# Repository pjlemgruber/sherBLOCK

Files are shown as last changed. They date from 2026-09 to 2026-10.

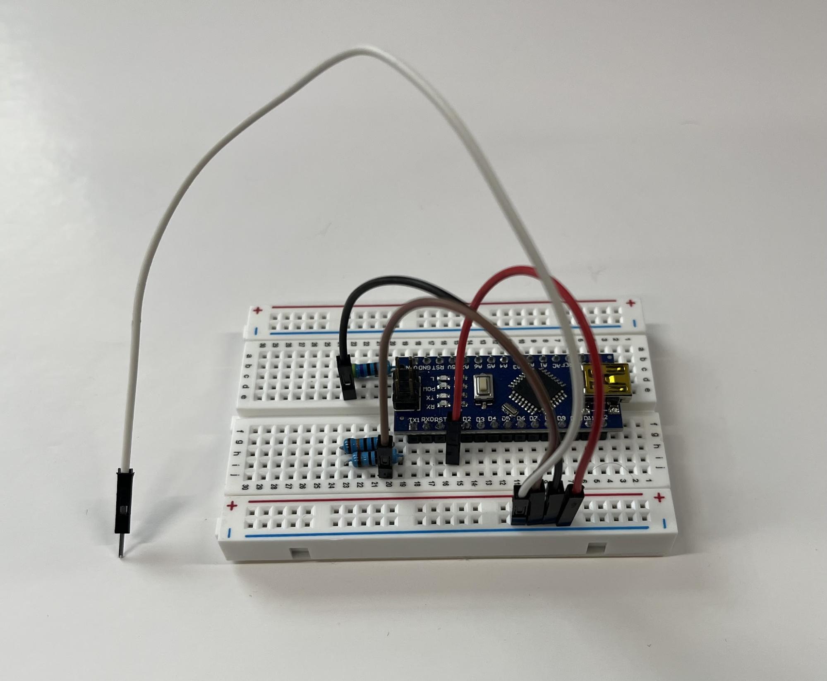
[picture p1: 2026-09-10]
images/image33.jpg

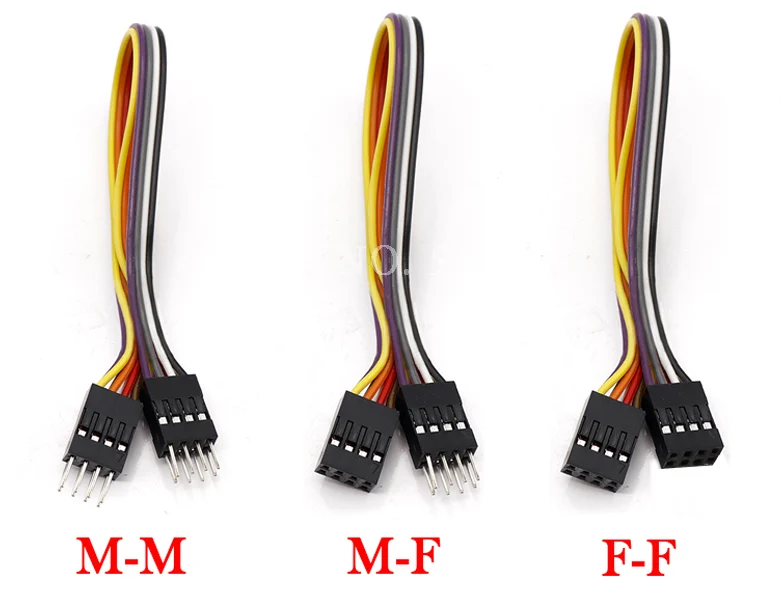
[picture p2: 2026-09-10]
images/image8.png

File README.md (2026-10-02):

# sherBLOCK

<p align="center">
sherBLOCK_5x
</p>

The sherBLOCK is a portable DIY isothermal heater designed for tube incubation in the field. It operates at 12V with a maximum power consumption of 24W, meaning it can be powered by a barrel jack wall adapter or a cigarette lighter car plug. The sherBLOCK is controlled by an Arduino Nano microcontroller, which can be programmed for user-specific modifications that best fit your project's needs. 

The sherBLOCK can be assembled to fit a variety of tube sizes (0.2, 0.5, 1.5, 5, and 15mL tubes). Other components, such as heaters, can also be replaced to meet your demands as long as they fit the sizing specifications of the enclosure. Components that deviate in sizing may require adjustments to the 3D printing files.



We welcome you to make modifications to the sherBLOCK and share them here so others can access them. 

This project is held under the GNU General Public Licence v3.0. Please keep in mind that by choosing to use or engage with the materials of this project, you are doing so at your own risk. The sherBLOCK includes heaters and sensitive electronics, making it a potential fire hazard. Please exercise caution when engaging with the materials provided here and use them responsibly.

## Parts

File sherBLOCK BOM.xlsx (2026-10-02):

sherBLOCK Bill of Materials (BOM) - 24W model |  |  |  |  |  |  | sherBLOCK+ Bill of Materials (BOM) - 80-120W model |  |  |  |  |  |  | Parts of interest for future steps
Materials | Bulk amount | Bulk cost | Amount | Cost | Supplier | Justification | Materials | Bulk amount | Bulk cost | Amount | Cost | Supplier | Justification | Parts | Notes | Link | Link 2 | Link 3
Interactive elements |  |  |  |  |  |  | Interactive elements |  |  |  |  |  |  | Buttons to program temperature/ time |  | https://www.aliexpress.us/item/3256806078303106.html?src=google&gatewayAdapt=glo2usa
Arduino Nano | 2 | $9.99 | 1 | $5.00 | LUIRSAY (https://www.amazon.com/LUIRSAY-2Pcs-ATmega328P-Microcontroller-Compatible/dp/B0F1FQMNXM?s=electronics) | Stores and executes the sherBLOCK code. | Arduino Nano | 2 | $9.99 | 1 | $5.00 | LUIRSAY (https://www.amazon.com/LUIRSAY-2Pcs-ATmega328P-Microcontroller-Compatible/dp/B0F1FQMNXM?s=electronics) | Stores and executes the sherBLOCK code. | Alternate temperature sensor |  | https://www.digikey.com/en/products/detail/dfrobot/DFR0198/7597054?gclsrc=aw.ds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 | https://www.dfrobot.com/product-1354.html
DS18B20 w/ adapter | 2 | $9.99 | 1 | $5.00 | DIYables (https://www.amazon.com/DIYables-Temperature-Raspberry-Waterproof-Stainless/dp/B0BPFYQT8C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) | Registers heating block temperature. | DS18B20 w/ adapter | 2 | $9.99 | 1 | $5.00 | DIYables (https://www.amazon.com/DIYables-Temperature-Raspberry-Waterproof-Stainless/dp/B0BPFYQT8C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) | Registers heating block temperature. | M3 Cap to keep feet level |  | https://www.amazon.com/50pcs-Acorn-Nylon-Decorative-Hexagon/dp/B0CFZR217S | https://www.aftfasteners.com/protective-cap-for-m3-screws-1-pkg/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
12V Heating Plate PTC | 4 | $16.19 | 1 | $4.05 | MECCANIXITY (https://www.amazon.com/MECCANIXITY-Polyimide-Insulated-Temperature-Thermostatic/dp/B0DYDSMS4J) | Heating element. | 12V Heating Plate | 4 | $16.29 | 1 | $4.08 | MECCANIXITY (https://www.amazon.com/MECCANIXITY-Polyimide-Insulated-Temperature-Thermostatic/dp/B0DXTP5M6D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) | High-power heating element. | Stronger heater |  | https://www.amazon.com/Bestol-Heating-consistant-Temperature-Thermostatic/dp/B07VBDT8NL | https://www.amazon.com/MECCANIXITY-Polyimide-Insulated-Temperature-Thermostatic/dp/B0DXTP5M6D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 | https://www.amazon.com/Electric-100x21x5mm-Heating-Element-Thermostatic/dp/B0FY6CPML9
OLED display | 1 | $21.00 | 1 | $21.00 | AITRIP (https://www.amazon.com/AITRIP-Display-SSD1309-Interface-C51-White/dp/B0G384SJ9V?s=electronics) | Displays sherBLOCK information | OLED display | 1 | $23.00 | 1 | $23.00 | AITRIP (https://www.amazon.com/AITRIP-Display-SSD1309-Interface-C51-White/dp/B0G384SJ9V?s=electronics) | Displays sherBLOCK information | Silicone sheet/foam |  | https://www.amazon.com/Exactly-Rubber-Commercial-Grade-Silicone/dp/B0B5V95MRG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 | https://www.amazon.com/LMS-Resistant-Silicone-Texture-Thickness/dp/B09YLRVL3M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 | https://www.ebay.com/itm/336449303839?chn=ps&var=545937298726&google_free_listing_action=view_item
Heat block | 1 | $35.99 | 1 | $35.99 | ONiLAB (https://www.amazon.com/dp/B0BHWKG5C8?tag=usdeexplicits-20&th=1) | Holds and heats up 0.5 mL tubes. | Heat block | 1 | $35.99 | 1 | $35.99 | ONiLAB (https://www.amazon.com/dp/B0BHWKG5C8?tag=usdeexplicits-20&th=1) | Holds and heats up 0.5 mL tubes. | Cork sheet |  | https://www.gigaparts.com/2mm-cork-sheet-4pcs-b-yl001.html?gigadv=P_Max_Best_Prod_Loc_CPA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
Wiring |  |  |  |  |  |  | Mica sheet | 240x150mm | $5.99 | 40x40mm | $0.33 | YQBOOM (https://www.amazon.com/YQBOOM-Waveguide-Universal-Microwave-150X120mm/dp/B0C3LTP2WX) | Insulation from heater. | IPP015N04NF2S | 10A rated logic level mosfet
12V Power Adapter | 1 | $7.29 | 1 | $7.29 | MTYTOT (https://www.amazon.com/100-240V-Converter-Compatible-5-5x2-1mm-Transformer/dp/B0CPLNHQZR?hvadid=693865273627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) | Provides 2A at 12V | Wiring |  |  |  |  |  |  | FQP30N06L | logic level mosfet to replace irf540N | https://www.amazon.com/dp/B0CBKDYHYJ?lv=shuf&channelId=500&plpRedirect=mhFallback
Female Power Jack DC | 5 | $4.99 | 1 | $1.00 | DIYables (https://www.amazon.com/dp/B0BPGC5GTQ?linkId=c76078686dfa517bb173c375dee38373&language=en_US) | Connects components to the power source. | 12V 10A Power Adapter 2.5x5.5mm | 1 | $22.00 | 1 | $22.00 | COOLM (https://www.amazon.com/12V-10A-Power-Suppy-Adapter/dp/B07FFKL7CR) | Provides the citcuit with 10A at 12V.
MOSFET IRF540N N-Channel | 10 | $7.99 | 1 | $0.80 | ALLECIN (https://www.amazon.com/ALLECIN-Transistors-IRF520NPBF-N-Channel-Transistor/dp/B0CBKGPJML) | Controls the power supply to the heating block. | 10A Power Jack connector | 1 | $1.86 | 1 | $1.86 | DigiKey (https://www.digikey.com/en/products/detail/same-sky-formerly-cui-devices/PJ-082BH/3477156) | Connects components to the power source.
Breadboard | 3 | $5.98 | 1 | $2.00 | ELEGOO (https://www.amazon.com/ELEGOO-400-Point-Solderless-Breadboard-Power/dp/B01EV640I6) | Boards for prototype assembly. | MOSFET IRLB3813 | 1 | $2.81 | 1 | $2.81 | Digikey (https://www.digikey.com/en/products/detail/infineon-technologies/irlb3813pbf/2118485) | Controls the power supply to the heating block. | Parts used or considered in the past | Amount | Cost | Supplier | Justification
Jumper wires | 1 pack | $8.99 | 14 | $0.50 | DIYables (https://www.amazon.com/Female-Female-Raspberry-Breadboard-Projects/dp/B0DHGQSRQY) | Wires for the temporary board. | Breadboard | 3 | $5.98 | 1 | $2.00 | ELEGOO (https://www.amazon.com/ELEGOO-400-Point-Solderless-Breadboard-Power/dp/B01EV640I6) | Boards for prototype assembly. | On/Off switch | 1 | $1.49 | Jameco (https://www.jameco.com/z/R13-73B-R-02-Jameco-ValuePro-Rocker-Switch-SPST-ON-OFF-Quick-Connect-10-Amp-250-Volt-AC_316128.html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) | Manual control of the power supply.
18 AWG Stranded Wire | 100 ft | $16.95 | 1 foot | $0.17 | Jameco (https://www.jameco.com/z/3055-BR005-JVP-Jameco-ValuePro-18-AWG-Brown-Stranded-Tinned-Copper-Hook-Up-Wire-100-Feet_2171911.html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) | Connects high-voltage components. | Jumper wires | 1 pack | $8.99 | 14 | $0.50 | DIYables (https://www.amazon.com/Female-Female-Raspberry-Breadboard-Projects/dp/B0DHGQSRQY) | Wires for the temporary board. | 12V DC Cooling fan | 2 | $8.49 | DIYables (https://www.amazon.com/DIYables-Cooling-Arduino-ESP8266-Raspberry/dp/B0DHGNRVM9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) | Cooling of the heating block.
Buck converter | 1 | $6.99 | 1 | $6.99 | Seloky (https://www.amazon.com/Seloky-Adjustable-Step-Down-Converter-Voltmeter/dp/B0DM946DHG?hvadid=80745583330117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) | Converts voltage to match the input needs of the components. | 16 AWG Stranded Wire | 100 ft | $15.95 | 1 foot | $0.16 | Best Connections (https://www.amazon.com/BEST-CONNECTIONS-Automotive-Primary-Wire/dp/B0CCFRGN67) | Connects high-voltage components. | 12V 100W Silicone Heating Plate (non-PTC) | 1 | $18.99 | JSR (https://www.jsr2.com/product/4-x-4-100-x-100mm-100w-w-thermostat-80-deg-c-universal-silicone-heater-pad/) | Heating of the heating block.
2 Screw Barrier Block terminal | 1 | $0.89 | 1 | $0.89 | Jameco (https://www.jameco.com/z/GGE-20-2P-Jameco-ValuePro-Connector-Barrier-Strip-2-Position-10-9mm-Pitch-Screw-Straight-Panel-Mount-20-Amp_2336927.html) | Connects multiple components to individual nodes. | Buck converter | 1 | $6.99 | 1 | $6.99 | Seloky (https://www.amazon.com/Seloky-Adjustable-Step-Down-Converter-Voltmeter/dp/B0DM946DHG?hvadid=80745583330117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) | Converts voltage to match the input needs of the components. | 12V Power Adapter | 1 | $8.99 | TMEZON (https://www.amazon.com/TMEZON-Power-Adapter-Supply-2-1mm/dp/B00Q2E5IXW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) | Provides 2A at 12V
3 way PCB terminal | 10 | $7.99 | 1 | $0.80 | Meimom (https://www.amazon.com/Meimom-Pluggable-Terminal-Connector-Phoenix/dp/B0DMD3XL6Y?s=industrial) | Connects components to separate nodes. | 2 Screw Barrier Block terminal | 1 | $0.89 | 1 | $0.89 | Jameco (https://www.jameco.com/z/GGE-20-2P-Jameco-ValuePro-Connector-Barrier-Strip-2-Position-10-9mm-Pitch-Screw-Straight-Panel-Mount-20-Amp_2336927.html) | Connects multiple components to individual nodes. | Perforated board | 1 | $33.68 | Newark (https://www.newark.com/phoenix-contact/rpi-bc-int-pcb-set/perfboard-raspberry-pi-board/dp/83Y6979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) | Used for permanent wiring.
220 Ohm resistors | 100 | $5.99 | 1 | $0.06 | EDGELEC (https://www.amazon.com/EDGELEC-Resistor-Tolerance-Multiple-Resistance/dp/B07QK9ZBVZ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) | Regulates current. | 3 way PCB terminal | 10 | $7.99 | 1 | $0.80 | Meimom (https://www.amazon.com/Meimom-Pluggable-Terminal-Connector-Phoenix/dp/B0DMD3XL6Y?s=industrial) | Connects components to separate nodes. | Hookup Wire 22 AWG Stranded (7x30) Tinned Copper Green 0.062 Inch (OD) PVC 25 Foot 300V 105C | 1 spool | $2.24 | Jameco (https://www.jameco.com/z/3051-GR-JVP-Jameco-ValuePro-Hookup-Wire-22-AWG-Stranded-7x30-Tinned-Copper-Green-0-062-Inch-OD-PVC-25-Foot-300V-105C_2305287.html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) | Connects low-voltage components.
4.7k Ohm resistors | 100 | $5.99 | 1 | $0.06 | EDGELEC (https://www.amazon.com/EDGELEC-Resistor-Tolerance-Multiple-Resistance/dp/B07QJB3LGN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) | Regulates current. | 220 Ohm resistors | 100 | $5.99 | 1 | $0.06 | EDGELEC (https://www.amazon.com/EDGELEC-Resistor-Tolerance-Multiple-Resistance/dp/B07QK9ZBVZ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) | Regulates current. | Barrier Block terminal | 1 | $7.99 | uxcell (https://www.amazon.com/uxcell-Positions-Barrier-Terminal-TB-4504L/dp/B07DM83GZ5?hvadid=79989661100667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) | Connects multiple components to individual nodes.
100k Ohm resistors | 100 | $5.99 | 1 | $0.06 | EDGELEC (https://www.amazon.com/EDGELEC-Resistor-Tolerance-Multiple-Resistance/dp/B07QK9793W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) | Regulates current. | 4.7k Ohm resistors | 100 | $5.99 | 1 | $0.06 | EDGELEC (https://www.amazon.com/EDGELEC-Resistor-Tolerance-Multiple-Resistance/dp/B07QJB3LGN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) | Regulates current. | OLED display (would not turn on) |  |  | Hosyond (https://www.amazon.com/Hosyond-inches-Display-SSD1309-Arduino/dp/B0G2RFLG1L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)
Nuts and bolts |  |  |  |  |  |  | 100k Ohm resistors | 100 | $5.99 | 1 | $0.06 | EDGELEC (https://www.amazon.com/EDGELEC-Resistor-Tolerance-Multiple-Resistance/dp/B07QK9793W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) | Regulates current. | alternative OLED display | 1 | $14.00 | ACEIRMC (https://www.amazon.com/ACEIRMC-Display-SSD1309-Interface-Arduino/dp/B0C4SJ4QBF?cv_ct_cx=OLED%2BArduino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)
10mm M3 nylon screws |  |  | 4 | $0.08 |  | Can be replaced by 12mm ones. | Nuts and bolts |  |  |  |  |  |  | LCD display | 1 | $9.99 | Qunqi (https://www.amazon.com/Qunqi-Serial-Backlight-Arduino-MEGA2560/dp/B01E4YUT3K)
45mm M3 steel screws |  | $8.99 | 2 | $0.04 | VGBUY (https://www.amazon.com/VGBUY-440pcs-Assortment-Printer-Stainless/dp/B0D1XQCJPR) |  | 12mm M3 nylon screws |  | $9.99 | 10 | $0.20 | AvrestYPT (https://www.amazon.com/Plastic-Gaskets-Threaded-Washers-Assortment/dp/B0FMDSM1VG?hvadid=694064261167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) |  | Thermal paste | 1 | $6.99 | CoolerCube (https://www.amazon.com/Compound-Heatsink-Processor-Performance-Interface/dp/B09B53Q3QY?hvadid=79989590435842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) | Attaches heating elements.
65mm M3 steel screws |  | $10.00 | 4 | $0.80 | iexell (https://www.amazon.com/iexcell-Thread-Stainless-Socket-Screws/dp/B0DZGYRKZY) |  | 45mm M3 steel screws |  | $8.99 | 2 | $0.04 | VGBUY (https://www.amazon.com/VGBUY-440pcs-Assortment-Printer-Stainless/dp/B0D1XQCJPR) |  | Barrel Jack to Powerpole Adapter | 1 | $9.99 | POWERWERX (https://powerwerx.com/21mm-coaxial-socket-powerpole-adapter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)
20mm M5 screws |  | included | 4 | $0.08 |  |  | 65mm M3 steel screws |  | $10.00 | 4 | $0.80 | iexell (https://www.amazon.com/iexcell-Thread-Stainless-Socket-Screws/dp/B0DZGYRKZY)
M3 nylon hex nuts |  | included | 12 | $0.24 |  |  | 20mm M5 screws |  |  | 4 | $0.08
M3 steel hex nuts |  | included | 6 | $0.12 |  |  | M3 nylon hex nuts |  |  | 10 | $0.20 |  |  | SHERLOCK reagents cost
ASA filament and printed parts |  |  |  |  |  |  | M3 steel hex nuts |  |  | 6 | $0.12 |  |  | Reagents | Amount | Cost | Supplier | Justification
sherBLOCK base |  |  | 64g | $1.27 |  |  | Bulk ASA filament | 1kg | $20.00 |  |  |  | Check filament manufacturer's temperature specifications depending on sherBLOCK application. | T7 polymerase | 1 | $241.00 | New England Biolabs | Transcribes DNA to RNA.
sherBLOCK lid |  |  | 49g | $0.99 |  |  | sherBLOCK+ base |  |  | UPDATE | UPDATE |  |  | Ribonucleotide Solution | 1 | $276.80 | New England Biolabs | rNTPs for RNA synthesis and amplification.
Support for barrel jack adapter |  |  | 3.3g | $0.07 |  |  | sherBLOCK+ lid |  |  | UPDATE | UPDATE |  |  | RNase H | 1 | $273.60 | New England Biolabs | Degrades RNA in DNA-RNA hybrid
Tools for assembly |  |  |  |  |  |  | Support for 10A adapter |  |  | UPDATE | UPDATE |  |  | RNase Inhibitor Murine | 1 | $268.00 | New England Biolabs | Prevents RNA degradation by inhibiting RNases
Soldering iron |  |  |  |  |  |  | Tools for assembly |  |  |  |  |  |  | Twistamp Basic Kit | 1 | $475.12 | TwistDx | Rapid DNA amplification kit
Wire trimmer (10-18 AWG) |  |  |  |  |  |  | Soldering iron |  |  |  |  |  |  | Total cost of reagents: |  | $1534.52
3.0x30mm Phillips screwdriver |  |  |  |  |  |  | Wire trimmer (10-18 AWG)
3.0x30mm flathead screwdriver |  |  |  |  |  |  | 3.0x30mm Phillips screwdriver
Phillips screwdriver #2 |  |  |  |  |  |  | 3.0x30mm flathead screwdriver
Total cost: |  | $198.18 |  | $95.35 |  |  | Phillips screwdriver #2
 |  |  |  |  |  |  | Total cost: |  | $241.66 |  | $113.03
 |  |  |  |  |  |  |  | : Parts that differ between models

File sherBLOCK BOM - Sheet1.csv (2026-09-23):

SherBLOCK Bill of Materials
Materials | Bulk amount | Bulk cost | Amount | Cost | Supplier | Justification |  | Parts of interest for future steps | Link
Interactive elements |  |  |  |  |  |  |  | Buttons to program temperature/ time | https://www.aliexpress.us/item/3256806078303106.html?src=google&gatewayAdapt=glo2usa
Arduino Nano | 2 | $9.99 | 1 | $5.00 | LUIRSAY | Stores and executes the sherBLOCK code. |  | Alternative temperature sensor | https://www.digikey.com/en/products/detail/dfrobot/DFR0198/7597054?gclsrc=aw.ds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
DS18B20 w/ adapter | 2 | $9.99 | 1 | $5.00 | DIYables | Registers heating block temperature. |  | Alternative temperature sensor | https://www.dfrobot.com/product-1354.html
12V Heating Plate PTC | 4 | $16.19 | 1 | $4.05 | MECCANIXITY | Heating of the heating block. |  | M3 Cap to keep feet level | https://www.aftfasteners.com/protective-cap-for-m3-screws-1-pkg/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
OLED display | 1 | $21.00 | 1 | $21.00 | AITRIP | Displays sherBLOCK information |  | Stronger heater (non PTC) | https://www.amazon.com/Bestol-Heating-consistant-Temperature-Thermostatic/dp/B07VBDT8NL
Heat block | 1 | $35.99 | 1 | $35.99 | ONiLAB | Holds and heats up 0.5 mL tubes. | <-- Often in low stock
Wiring
12V Power Adapter | 1 | $8.99 | 1 | $8.99 | COOLM | Provides 2A at 12V
Female Power Jack DC | 5 | $4.99 | 1 | $1.00 | DIYables | Connects internal components to the power source.
MOSFET IRF540N N-Channel | 10 | $7.99 | 1 | $0.80 | ALLECIN | Controls the power supply to the heating block.
Breadboard | 3 | $5.98 | 1 | $2.00 | ELEGOO | Boards for prototype assembly.
Jumper wires | 1 pack | $8.99 | 14 | $0.50 | DIYables | Wires for the temporary board.
18 AWG Brown Stranded Tinned-Copper Hook-Up Wire 100 Feet | 1 spool | $16.95 | 1 foot | $0.20 | Jameco | Connects high-voltage components.
Buck converter | 1 | $6.99 | 1 | $6.99 | Seloky | Converts voltage to match the input needs of the components.
2 Screw Barrier Block terminal | 1 | $0.89 | 1 | $0.89 | Jameco | Connects multiple components to individual nodes.
3 way PCB terminal | 10 | $7.99 | 1 | $0.80 | Meimom | Connects components to separate nodes.
220 Ohm resistors | 100 | $5.99 | 1 | $0.06 | EDGELEC | Regulates current to prevent damage to components
4.7k Ohm resistors | 100 | $5.99 | 1 | $0.06 | EDGELEC | Regulates current to prevent damage to components
100k Ohm resistors | 100 | $5.99 | 1 | $0.06 | EDGELEC | Regulates current to prevent damage to components
Screws |  |  | 22 | $10
Nuts |  |  | 22 | $1
Total cost: |  | $180.89 |  | $93.39
Tools and other associated costs
Soldering iron
ASA printing material |  | $10.00

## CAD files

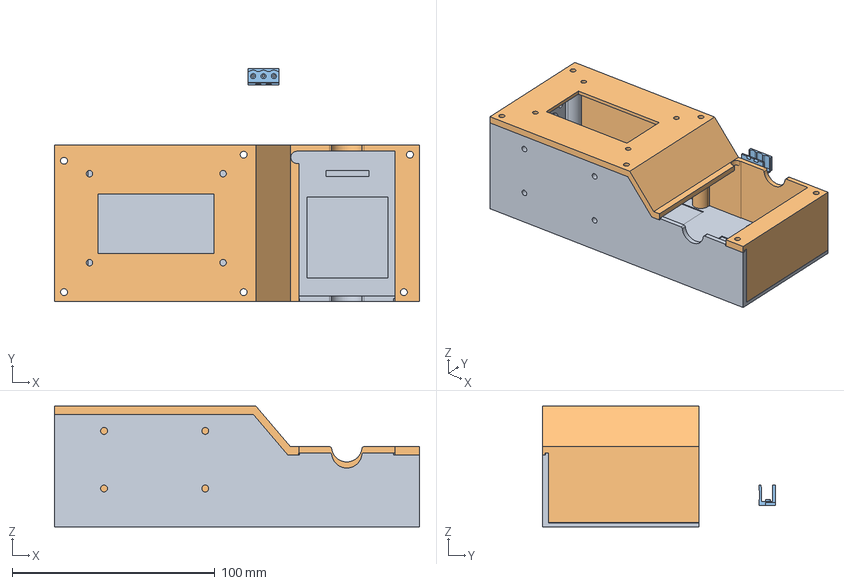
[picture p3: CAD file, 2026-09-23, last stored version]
sherBLOCK v5.FCStd
180.0 x 115.1 x 59.5 mm
Base body001
Lid body001
HT-508-case

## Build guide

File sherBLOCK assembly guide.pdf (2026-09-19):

### sherBLOCK assembly guide

Updated on 09/18/2026

A Bill Of Materials (BOM) for the sherBLOCK can be found in the GitHub page. (https://github.com/pjlemgruber/sherBLOCK)

For some great visuals and more extensive explanations, check out this guide by Sparkfun (https://cdn.sparkfun.com/datasheets/Kits/SFE03-0012-SIK.Guide-300dpi-01.pdf) on getting started with Arduino boards and breadboard circuit assembly.

### 1. Arduino IDE setup

a. Download the Arduino IDE (http://arduino.cc/en/Main/Software) This is where you will paste the Arduino code. Once the code runs later on, the IDE will import the libraries and drivers needed and then upload the code to the Arduino Nano board. This code will then be stored in the Arduino Nano and will only need to be re-uploaded if you want to implement modifications.
b. Connect the Arduino Nano to your computer Plug in the Arduino Nano board to your computer, open Arduino IDE and select the dropdown menu. This will require a cable that connects to your laptop ports and has a USB Mini B port to connect to the Arduino Nano. Then, click “select other board and port”, select the board “Arduino Nano” and then choose an available port. At the bottom right of the app you should see “Arduino Nano on COM# [connected]”. If you are having port issues when uploading the code, that means that the port you selected is not the one your board is connected to, so try the other ports as well.
c. Open sketch and upload
After downloading the Arduino sketch from the sherBLOCK GitHub page, select “file” in the Arduino IDE, then “open” and open the sketch you downloaded.

At the top of the sketch you will see a few libraries needed to execute the code. These need to be downloaded within your Arduino IDE application before you can upload the code to the Arduino board. Select the bookshelf icon on the left hand sidebar to access the library manager, then copy and paste the names of the libraries included in the code (first few lines) in the search bar. When downloading the main libraries, include any dependencies if prompted.

Now click on the right facing arrow on the teal bar to upload the code to the Arduino board.

If you experience any issues when attempting to upload the code to the Arduino, first try searching the exact problem you ran into. There is a lot of great troubleshooting advice out there and someone has likely already provided a solution to most common problems. One common issue is that the Arduino Nano clone might need an old version of the bootloader. For

Updated on 09/18/2026

that, click on “Tools” on the top menu, then “Processor”, and select “ATmega328P (Old bootloader)”. Try uploading again after switching the processor.

If you cannot get through the uploading step, feel free to reach out to us on GitHub for support.

### 2. Assembling the circuit

* Disconnect the Arduino from any power supply before starting *

Before you start making connections on your breadboard, make sure you are familiar with the following:

The breadboard:

Key points:

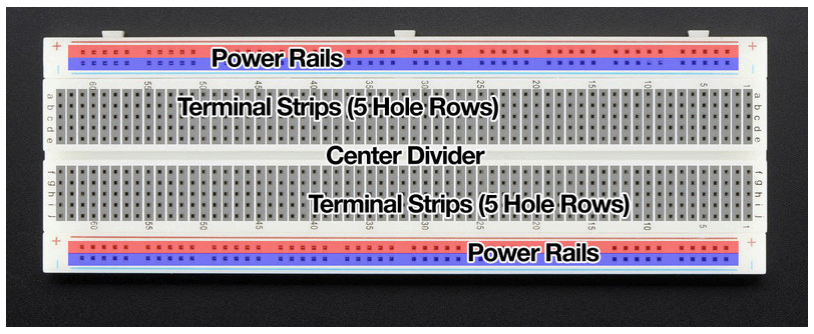
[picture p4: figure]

- Each 5-hole row (terminal strip) is internally connected by a metal strip.
- The center divider splits the breadboard into two disconnected sides.
- Each hole in a terminal strip can be referred to by a letter and number coordinate found on either side of the strips. These coordinates make assembly much easier.
- Each power rail is internally connected along the length of the breadboard, but not to any of the other power rails.
- The + and - signs on the power rails are only labelling, but are still usually used for the corresponding + and - connections.

Updated on 09/18/2026

- + and - refer to the directions of the current in the circuit, where current flows from the + side of the power source (higher voltage) to the - side (lower voltage). Therefore, the + rail is commonly used for connections from the power source to the components, and the - rail is used for closing the circuit and connecting back to the power source.
- Jumper cables can have different combinations of male and female ends. Here, M/M, F/M, F/F will be used to indicate the cable type needed for each connection.

Important

- Never work on a circuit that is connected to a power supply (live circuit)! Always disconnect the power before adjusting individual components.
- Make sure to not connect more than one pin of a component to a single interconnected strip. This will create a path of very little resistance that drastically increases the current flowing through it, producing heat and potentially breaking components (a short circuit). Relevant examples of connections to avoid are connecting the + rail with the - rail, and connecting multiple pins of one component to the same terminal strip (row of holes).
- Use the different colors and positions of the jumper wires to organize the board as you are assembling it. Avoid a jumble of wires by having them go around each other rather than under and over when possible.

Assembling the breadboard:

Updated on 09/18/2026

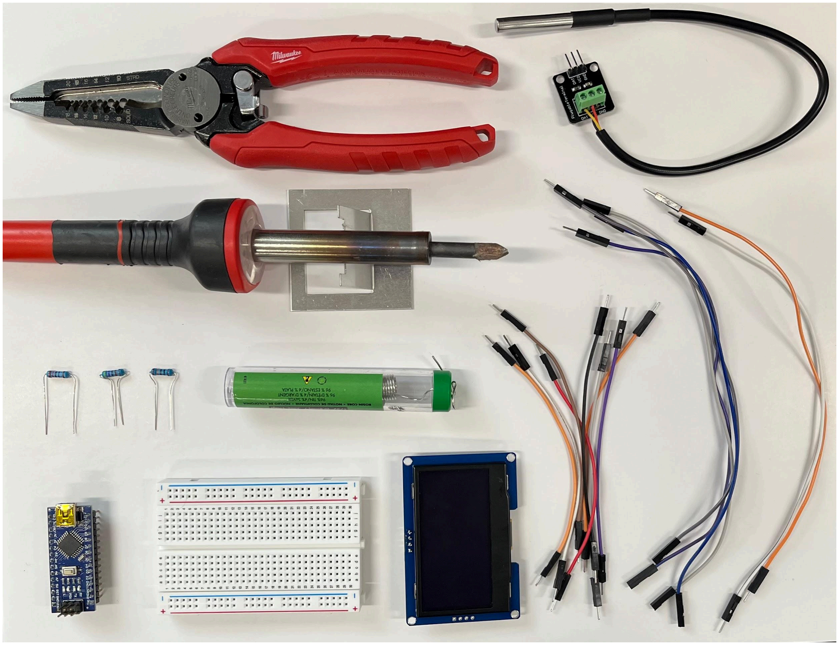
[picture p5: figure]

1. Place the Arduino Nano board with the outermost pins on the port side on C4 and G4 (the outermost pins on the other side of the board should be on C18 and G18). Press it down evenly to click into place.
2. Adding resistors
a. Grab a 4.7K ohm resistor (has a yellow stripe) and bend its legs so that it forms a U shape. Now press the base of each leg against the resistor so that they are closer together while still parallel at the ends (you want them to be able to attach to neighboring holes). You may want to trim around 15mm from the ends of the legs so that the resistor sits closer to the board when you attach it, but test the resistor on any holes on the board before you trim to avoid over-trimming. Now attach one leg to C22 and the other to C21 (either orientation works).

Updated on 09/18/2026

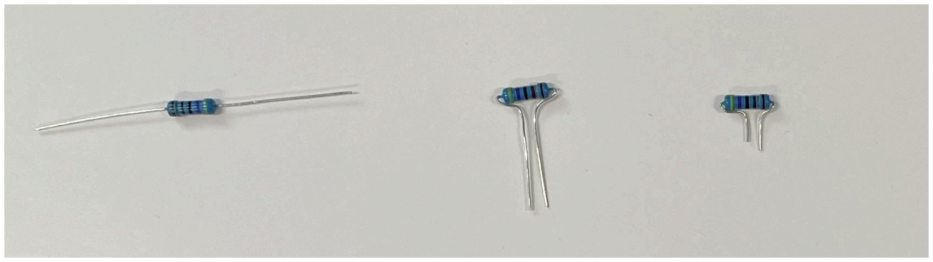
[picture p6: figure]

b. Now grab a 100K ohm resistor (has an orange band). This resistor will attach to holes separated by two holes (will span four holes in total), so do as above but with a smaller deviation from that U shape. Trim the ends as before. Attach to H23 and H20.

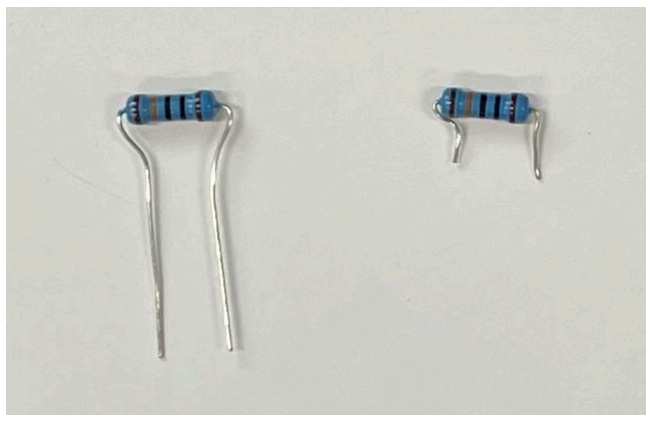
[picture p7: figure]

c. For the last resistor, grab a 220 ohm resistor (has two red bands). This one will span five holes, so you can simply make that U shape and trim the ends. Attach to I23 and I19.

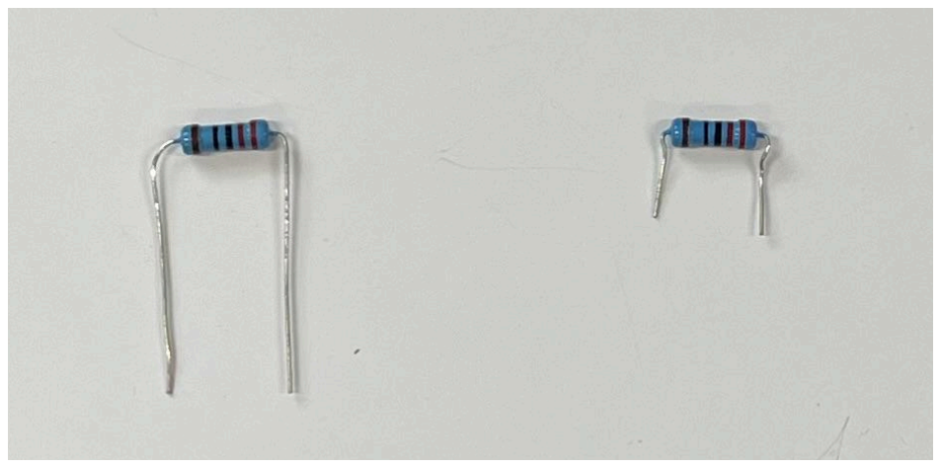
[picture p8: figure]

3. Building the common ground (-) rail:

Updated on 09/18/2026

a. Connect a short M/M jumper cable to the second column of the right side - rail and to I15 (which should be in the same row/ terminal strip as the Arduino GND pin).
b. Connect another short M/M cable to E23 and the same - rail column as the previous wire.
c. Connect another short M/M cable to the same - rail column and J20
d. Connect a long M/M jumper cable to that same - rail and leave the other end unattached

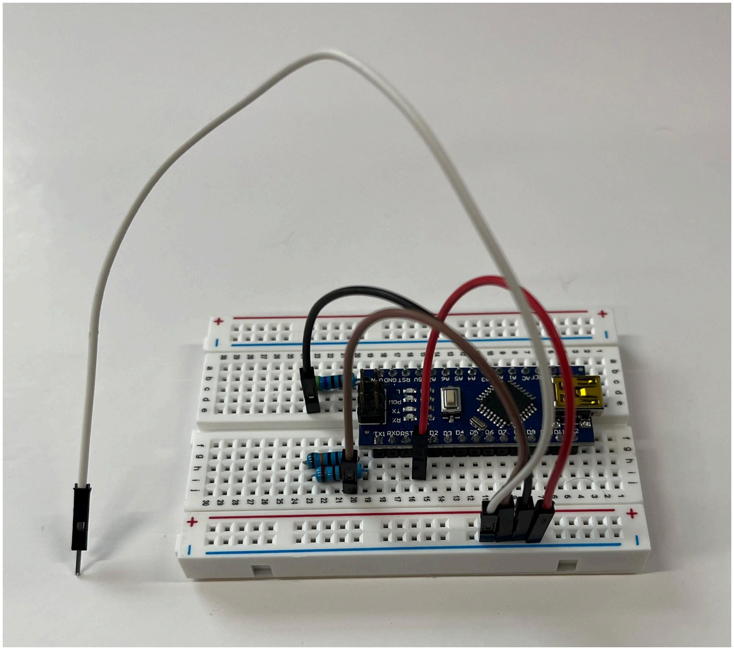
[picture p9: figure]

4. Building the 5V + rail:
a. On the same side of the board as the - rail, connect a short M/M cable to the third column down on the + power rail. The other end connects to A15 (same terminal strip as the Arduino 5V).
b. Connect another short M/M jumper cable to that same + column and to E22.
c. Now connect a long M/M jumper cable to the + rail column and leave the other end disconnected.

Updated on 09/18/2026

5. Connecting to the arduino:
a. Connect a short M/M jumper cable to E21 and to I14 (same row as the arduino D2 pin).
b. Connect another short M/M cable to I11 (same row as the arduino D5 pin) and to J19.
c. Connect another short M/M cable to J23 and leave the other end unattached.

Updated on 09/18/2026

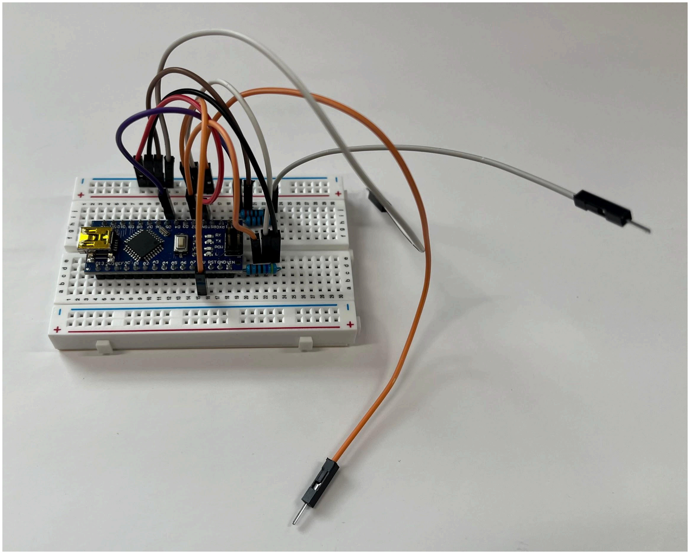
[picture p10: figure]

6. Connecting the OLED screen:
a. Before connecting jumper wires to the OLED, you will first need to solder the pins it comes with to its board. There are many short videos out there that do an excellent job at teaching beginners how to start soldering. One tip is to practice with jumper cables and resistors as you watch since you will likely have them in excess. This step can be more challenging than the rest of the assembly, so take your time with it and attempt it once you feel ready (you can return to this step later on). Avoid touching the screen with a hot soldering iron as it can ruin it.
b. Please check the pin names on the back of the board before soldering. The pins you want are GND, VDD, SCL, and SDA. If there are two rows of pins to choose from, we recommend using the top center one. Make sure that the black plastic strip for the pins is on the back of the screen’s board with the long side of the pins facing back. This way, the short side of the pins should be going through the board with their ends sticking out front only a few millimeters; you will add the solder to these pin ends from the top side of the screen.

Updated on 09/18/2026

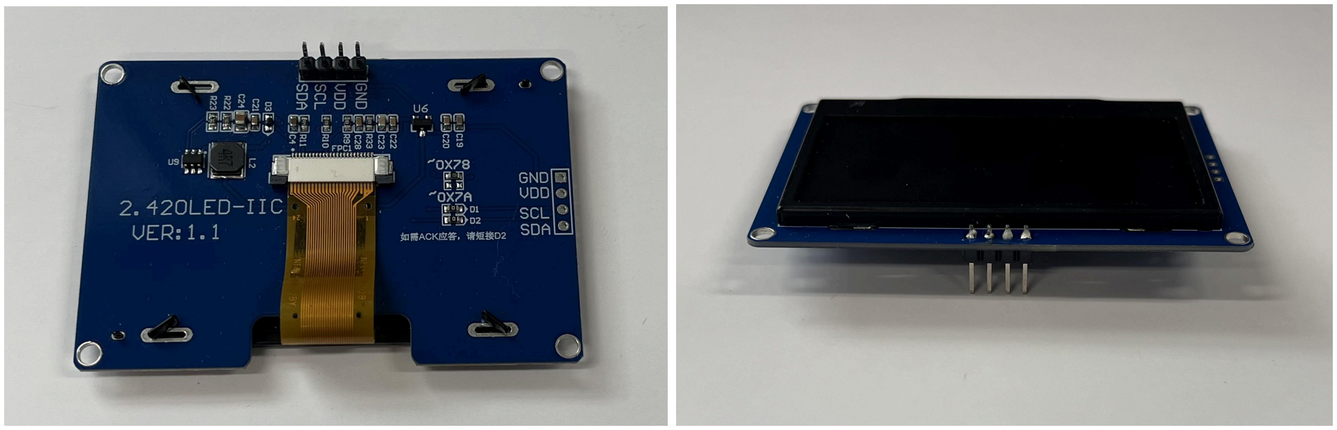
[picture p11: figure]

c. Once the pins are secured to the OLED screen, grab four F/M long cables and attach the female end to the OLED pins. Connect the male ends from the SDA and SCL pins to A11 and A12 respectively. Connect the VDD cable to the 5V + rail. Connect the GND cable to the common ground (-) rail.

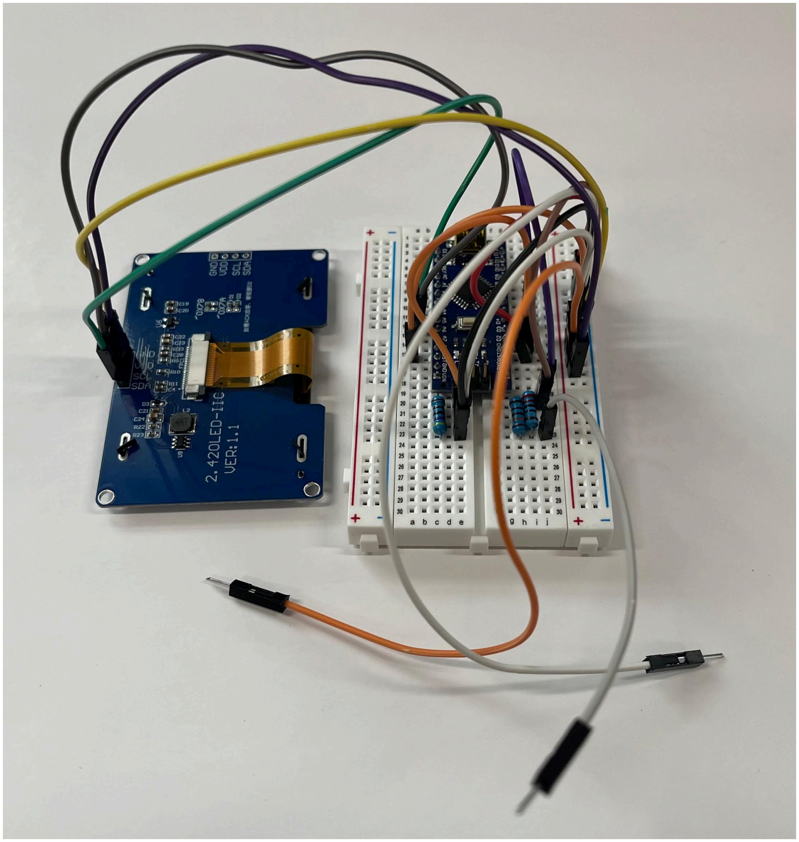
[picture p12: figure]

7. Connecting the temperature sensor:
a. Now it’s time to get out the wire strippers for some practice. The Temperature sensor used in this build has a much longer wire than needed, so before cutting

Updated on 09/18/2026

it to its desired length we suggest trying a few trimmings before. This will involve cutting a section of the external wire casing (black) without damaging the thin internal wire leads, then stripping the ends of the internal leads without
damaging the internal strands. Most wire trimmers will not have a setting for larger gauges than 20 AWG, so you will need to use the trimmer’s blades or another sharp blade to make delicate cuts around the leads.

“Measure twice, cut once.”

b. Once you feel confident about trimming the small leads, cut the sensor to around 280mm from end to end.
c. Now, strip 15mm of the black insulating casing, then strip 5mm from the ends of each colored lead. Twist the strands of each lead to get rid of stray strands.
d. Insert the twisted lead strands into their respective connections on the adapter that comes with the temperature sensor. The black wire connects to GND, red to VCC, and yellow to DAT.

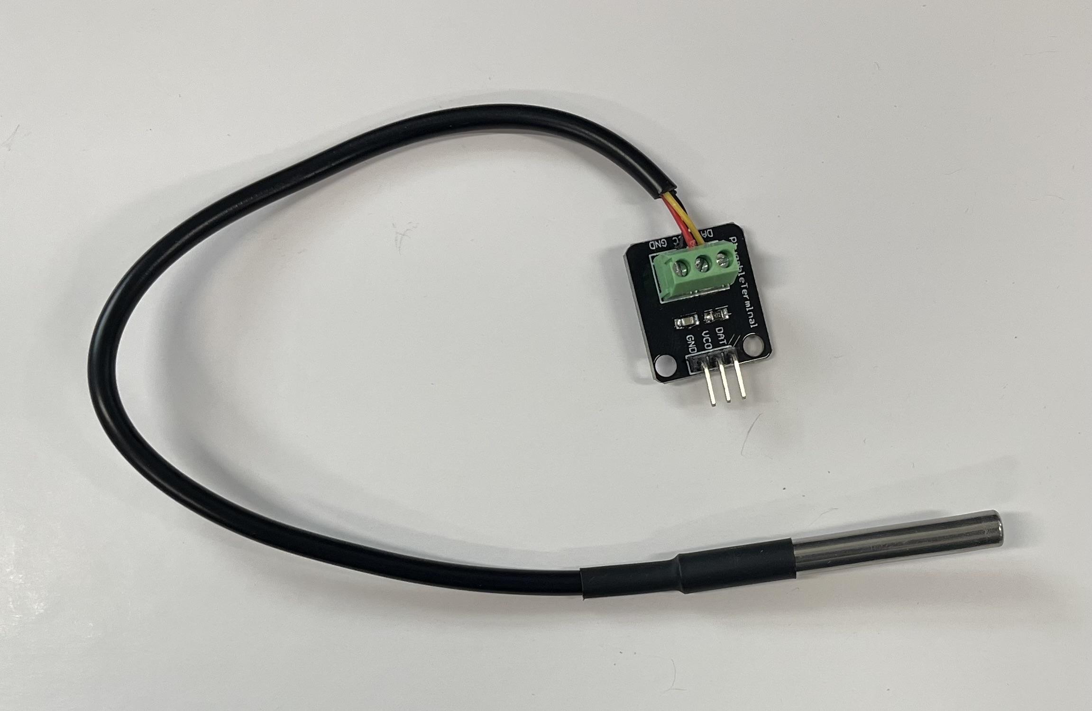
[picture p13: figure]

e. Connect the adapter’s pins to the breadboard. The GND pin connects to A23 (VCO and DAT should connect to A22 and A21 respectively).

Updated on 09/18/2026

Updated on 09/18/2026

Assembling the remaining circuit:

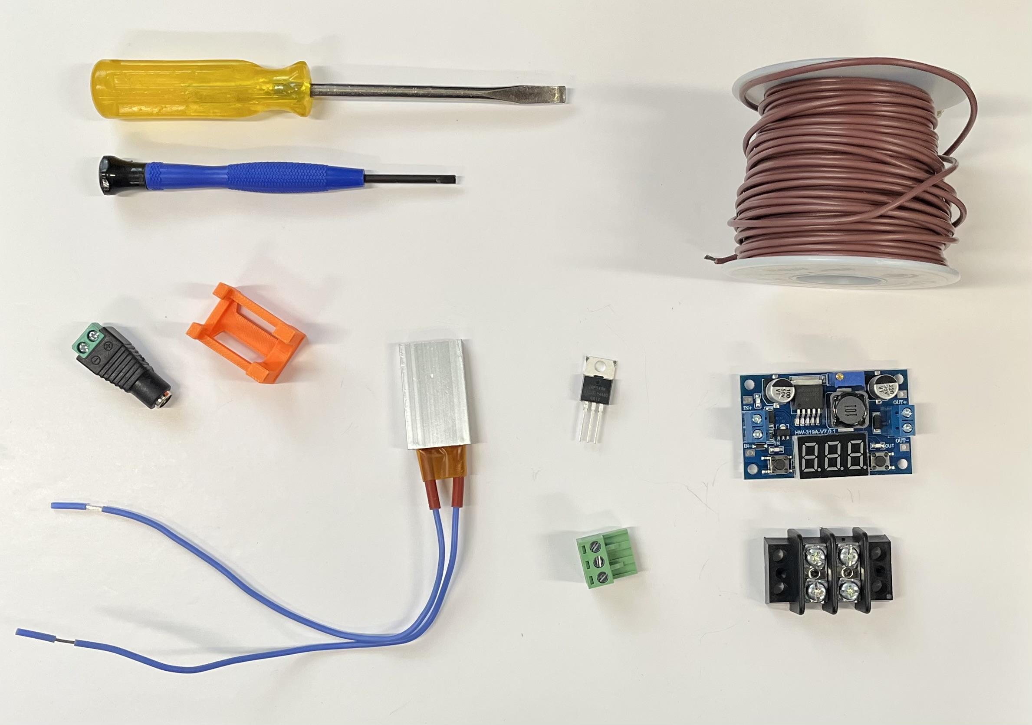
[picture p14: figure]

* Avoid leaving more than 2mm of exposed wire strands when making connections as exposed wires can lead to a short circuit.

1. Cut two 30mm, two 60mm, and one 85mm pieces of 18 AWG wire. Strip around 8-10mm from each end and twist the ends tightly to prevent loose strands.
2. With the screws of a block terminal facing you, loosen all four screws to open space for the wires. You will insert the twisted strands on the sides between the two metal plates to make connections across the terminal block.

Updated on 09/18/2026

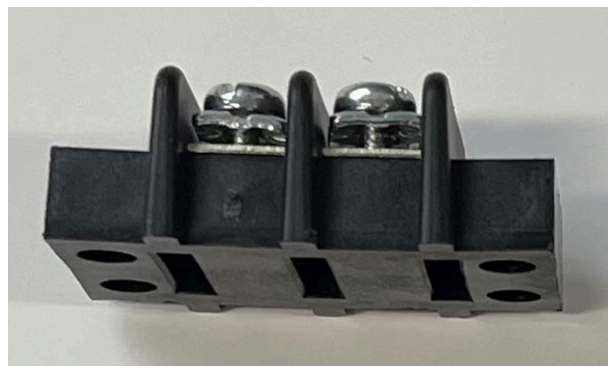
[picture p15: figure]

3. Connect one end of each 60mm wire to each opening on one side of the terminal block. Tighten the screws on the right side and perform a tug test on each wire to check if they are firmly in place.

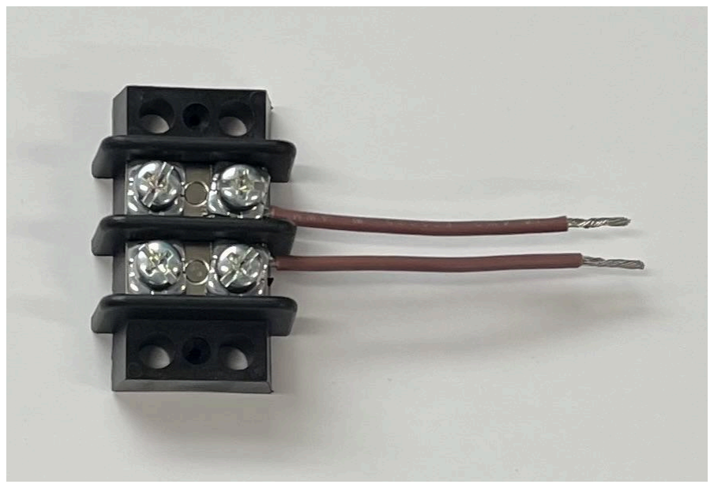
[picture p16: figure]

4. Now connect the other end of the top wire to the (-) connection on the female barrel jack adapter and tighten the screw to secure the wire. The bottom wire connects to the (+) connection. Tug test both wires to check if they are secure.
5. Place the barrel jack adapter inside its 3d printed enclosure.

Updated on 09/18/2026

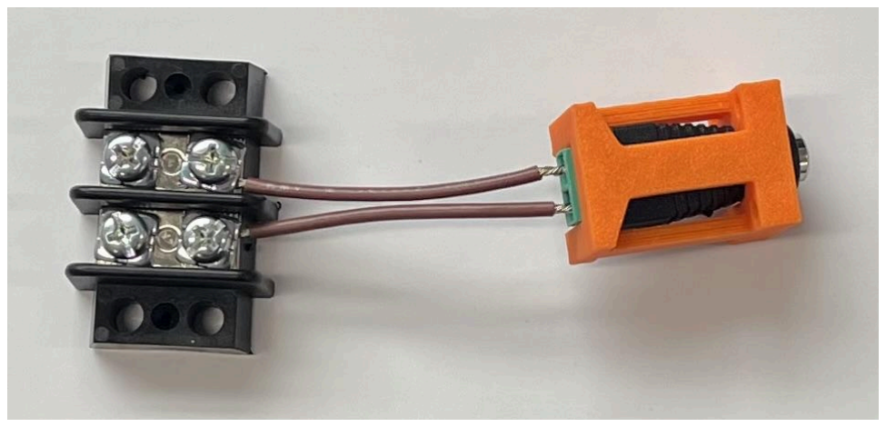
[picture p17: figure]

6. Before handling the MOSFET, ground yourself by touching a grounded metal object (such as a refrigerator or a washer) to prevent damaging it. Grab a 3 pin PCB terminal and bend the MOSFET legs slightly so that they slide into the 3 PCB connections. The MOSFET legs will share these pins with the following wires.

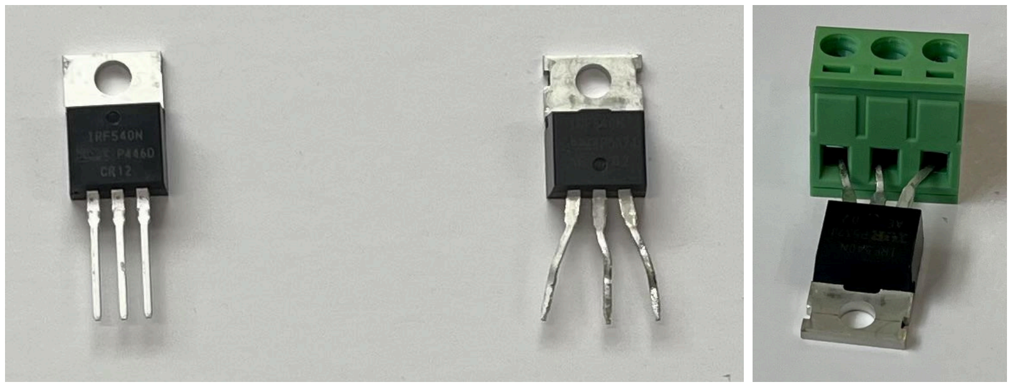
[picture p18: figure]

7. With the black tab on the MOSFET facing you, connect the 85mm wire you previously prepared to the rightmost connection pin of the PCB terminal. Tighten the screw for that pin.
8. Trim 2mm off of one of the heater’s wires and connect it to the middle connection on the PCB terminal. Tighten the screw for that pin.
9. Connect the loose end of the jumper cable on J23 to the leftmost pin on the PCB terminal. Tighten the screw for that pin.

Updated on 09/18/2026

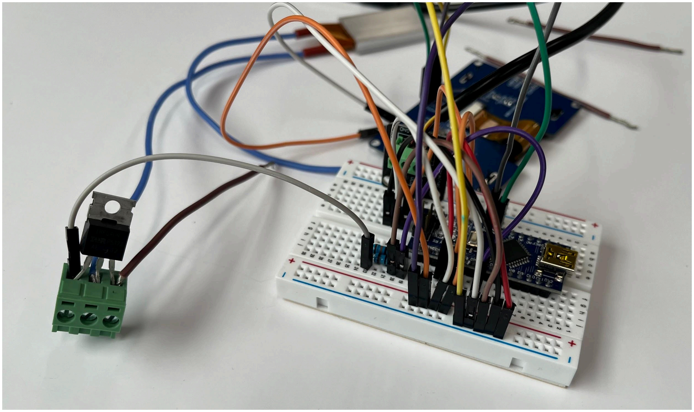
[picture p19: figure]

10. Perform a tug test on each wire to check that they are firmly in place.
11. Loosen all four screws on the Buck Converter. Connect one end of the 30mm wires to each opening on the IN side. Tighten the screws and tug test.
12. Connect the loose ends of the IN- wire from the Buck Converter and of the 85mm wire from the rightmost PCB pin to the top left opening of the terminal block. Tighten the screws and tug test.

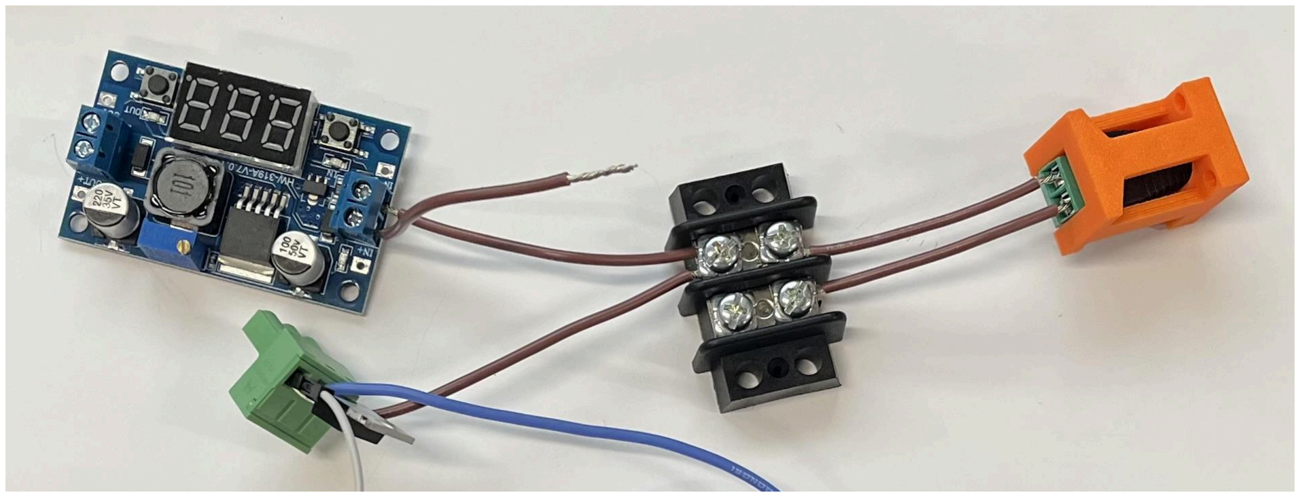
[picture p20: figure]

13. Connect the loose ends of the IN+ wire from the Buck Converter and the other wire from the heater to the bottom left opening of the terminal block. Tighten the screws and tug test.

Updated on 09/18/2026

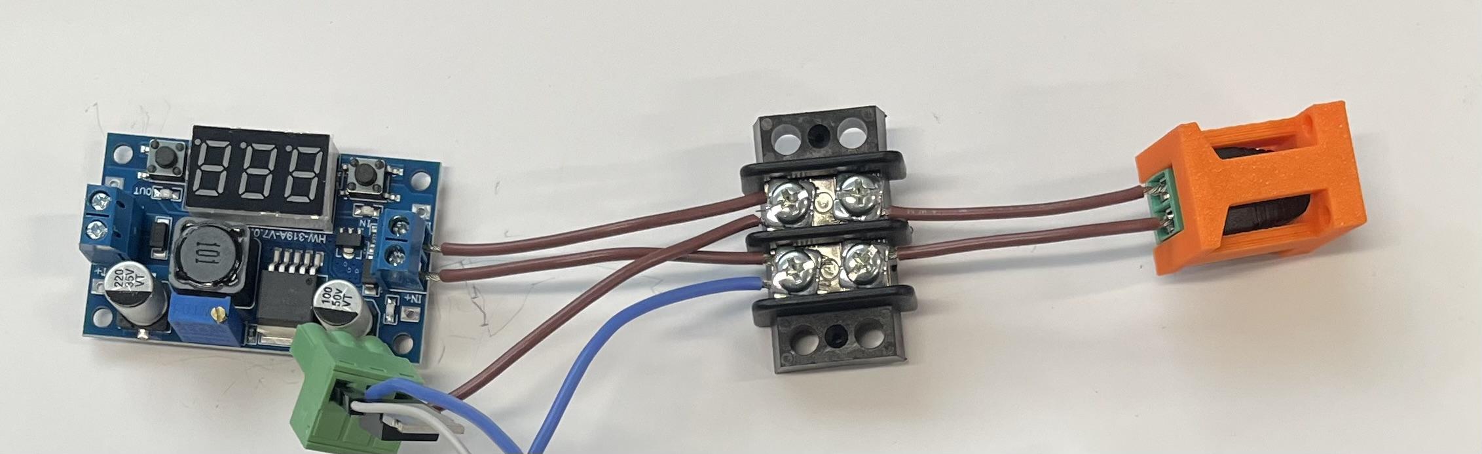
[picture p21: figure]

14. Finally, connect the loose ends of the + and - power rails of the breadboard to the respective OUT+ and OUT- connections on the Buck Converter. Tighten the screws and tug test.

With that, your circuit should be complete. Before powering it on, we recommend briefly going through each connection again to ensure no shorts will occur. As you move forward, pay attention to any smoke/erratic behavior or heat buildup on the wires. If you spot anything unusual, turn everything off before inspecting or changing connections.

First, power on the arduino directly through the USB Mini-B port; this should turn on all breadboard components (i.e. not the heater). If one/all do not turn on, start troubleshooting by rechecking your connections.

If the components turn on, you can now unplug the Arduino and power the circuit directly through the barrel jack adapter. This should also turn on the heater, so be careful as it will get very hot in only a few seconds.

Updated on 09/18/2026

It is important that the breadboard is receiving 5V or less so that the arduino board does not overheat. To check the voltage coming out of the buck converter, click the top right button to show the voltage (if not on already). Then, press the left button to show the voltage on the OUT side of the converter. There are small red LEDs that will light up on the side the display is showing information for. The voltage for the IN side should be around 12V, and around 5V for the OUT side. If the voltage for the OUT side is much higher than 5V, unplug the sherBLOCK and disconnect one of the OUT+/- wires from the breadboard before proceeding. Then, using a screwdriver you can turn a small brass screw (potentiometer; found at the bottom of the buck converter) counterclockwise in order to decrease the voltage. If the voltage on both sides is now close to the desired levels when turned on, you can continue the assembly.

Before proceeding with the assembly, turn everything off.

Putting everything together

Updated on 09/18/2026

Before you place the components inside the 3d-printed enclosure, prime each screw hole by fully screwing in its respective screw type. Different printers, materials, and brands produce different small deviations and imperfections that can make getting longer screws in much harder. It is better to prime the holes before you have more sensitive components inside.

1. Grab four 12mm M3 non-conductive screws and four non-conductive M3 hex nuts. Place the buck converter on the support structures of the long wall of the enclosure base with the IN ports facing the other base wall. Secure it with the screws and make sure the nuts are not loose.
a. Since bottom screws can be hard to reach, we recommend starting with the top screws. Once in place, hold the hex nuts on the bottom screws with one finger and turn the screw rather than directly tightening the hex nut on the screw.

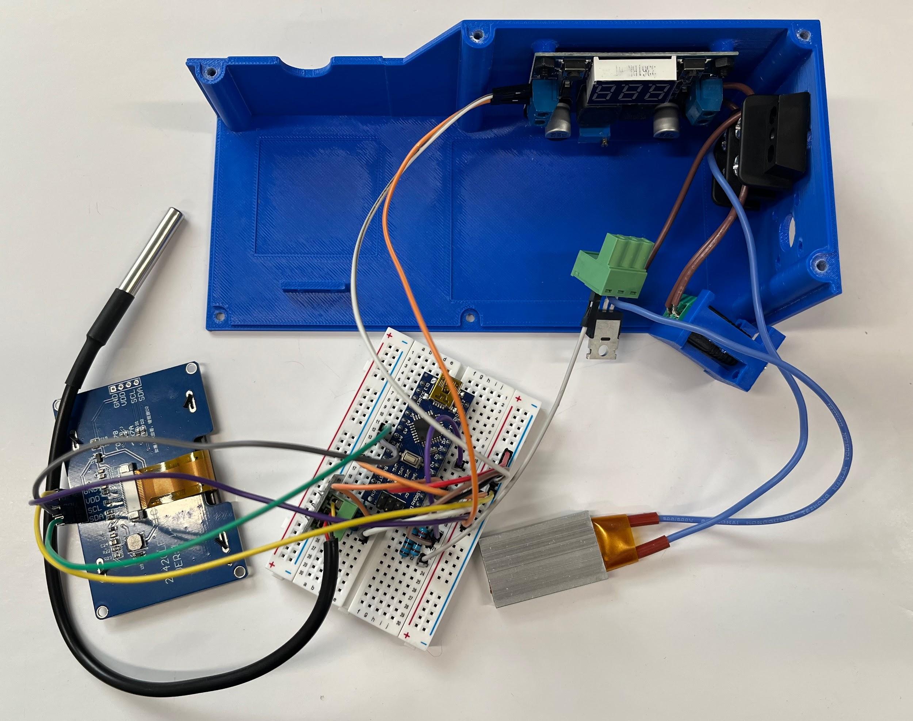
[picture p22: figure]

2. Now grab four M5 screws and tighten the block terminal in place on the shorter base wall. You may need to push the terminal against the wall while tightening to prevent a large gap from forming (a small gap is fine). It may be easier to start with the bottom left screw and then tighten the top right screw to prevent the block from tilting.

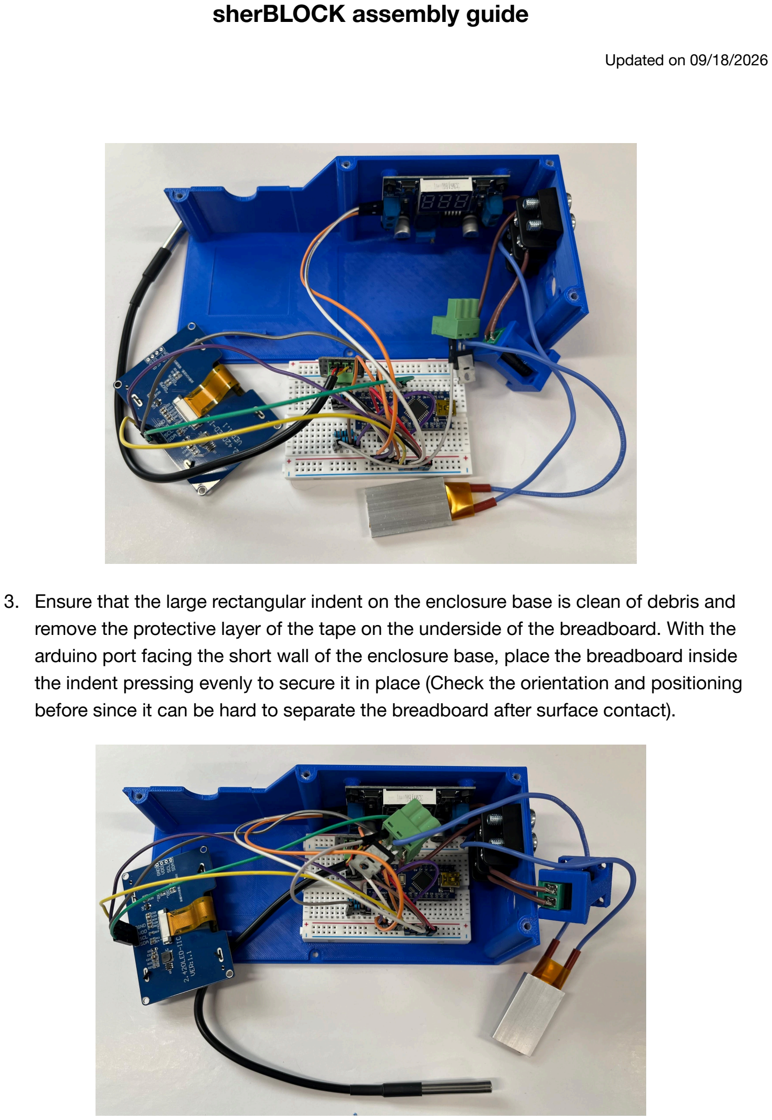
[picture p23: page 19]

Updated on 09/18/2026

3. Ensure that the large rectangular indent on the enclosure base is clean of debris and remove the protective layer of the tape on the underside of the breadboard. With the arduino port facing the short wall of the enclosure base, place the breadboard inside the indent pressing evenly to secure it in place (Check the orientation and positioning before since it can be hard to separate the breadboard after surface contact).

Updated on 09/18/2026

4. Now grab four more 12mm M3 screws (any material) and M3 hex nuts. Place the female barrel jack adapter and its enclosure on the 5-hole opening on the short base wall. The end of the adapter should be somewhat flush with the outside wall of the enclosure. Tighten the screws to secure it in place. As with the buck converter, it is easier to hold the nut in place and rotate the screws due to the surrounding parts.

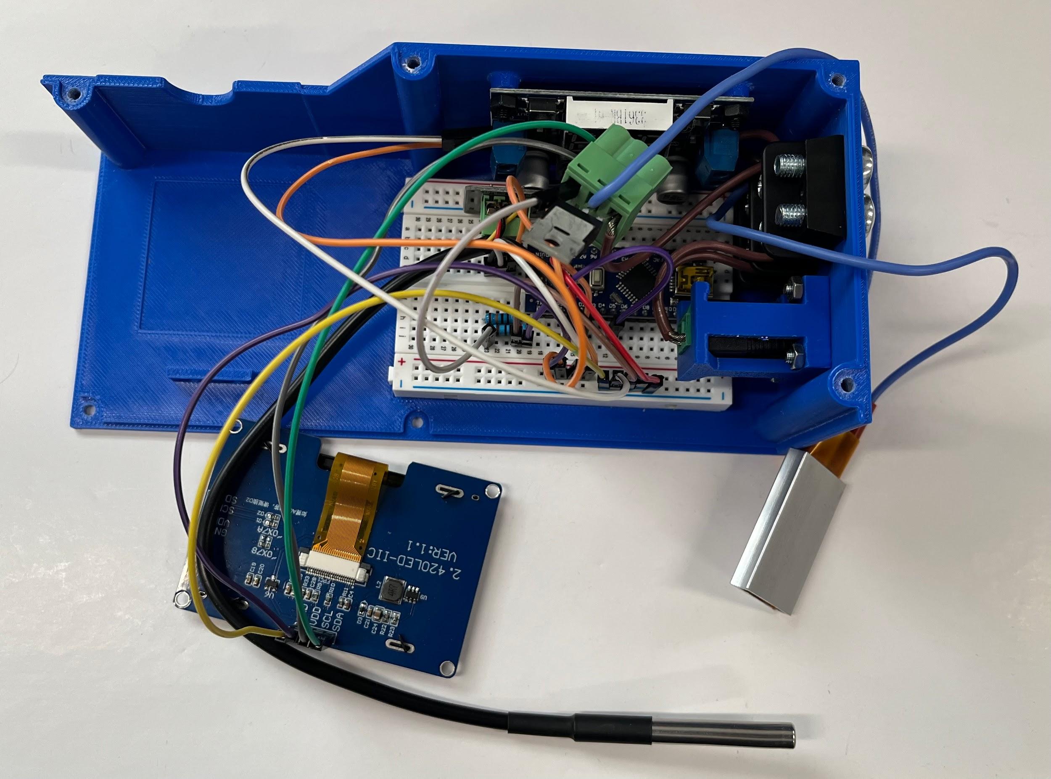
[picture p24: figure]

5. Cut a square of the silicone sheet smaller than 40x40mm so that it fits inside the square shaped indent on the base of the enclosure.
6. Grab the thinner blue portion of the heater wires and push it through the top opening next to the silicone sheet. Then, pull the thicker red/orange heater wire casing into the support structure. The heater should now be mostly centered on the silicone pad. Adjust as needed.
a. Do not worry if the heater is not fully touching the silicone sheet. Once the heating block is added, the heater should be evenly pushed against the base.

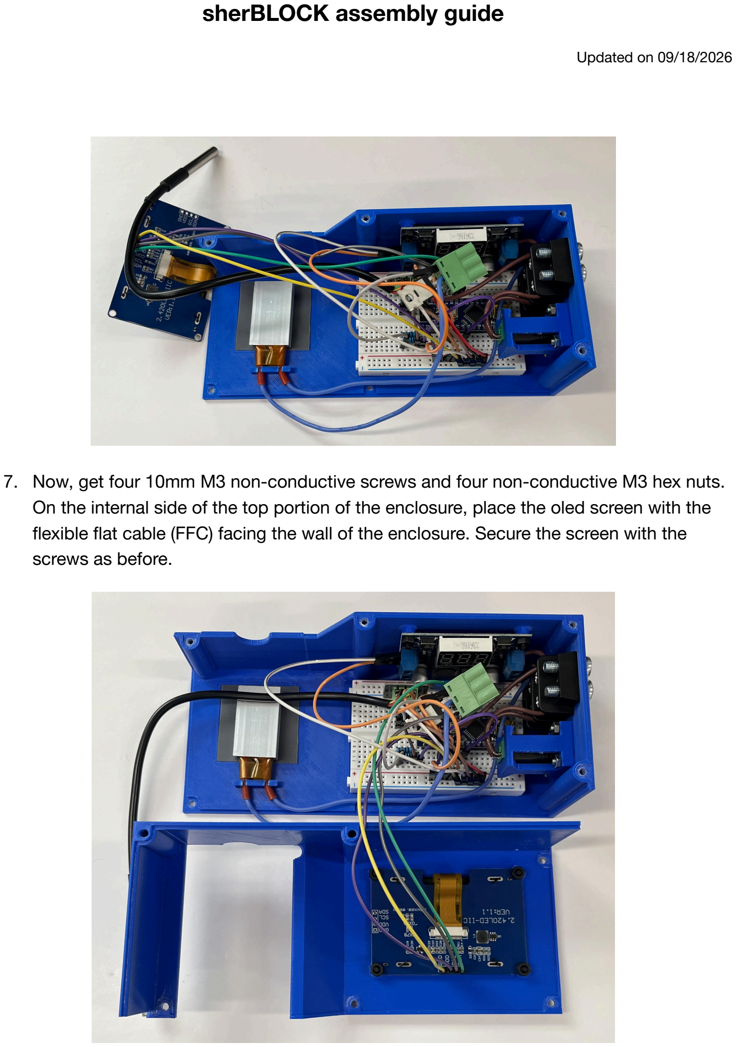
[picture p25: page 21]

Updated on 09/18/2026

7. Now, get four 10mm M3 non-conductive screws and four non-conductive M3 hex nuts. On the internal side of the top portion of the enclosure, place the oled screen with the flexible flat cable (FFC) facing the wall of the enclosure. Secure the screen with the screws as before.

Updated on 09/18/2026

8. Before securing the two halves of the enclosure, ensure that all wires are away from the heater and that the MOSFET is secured within the jumper cables and away from other metallic objects. Also quickly plug in the circuit to ensure that no connections got loose or shorted during the assembly.

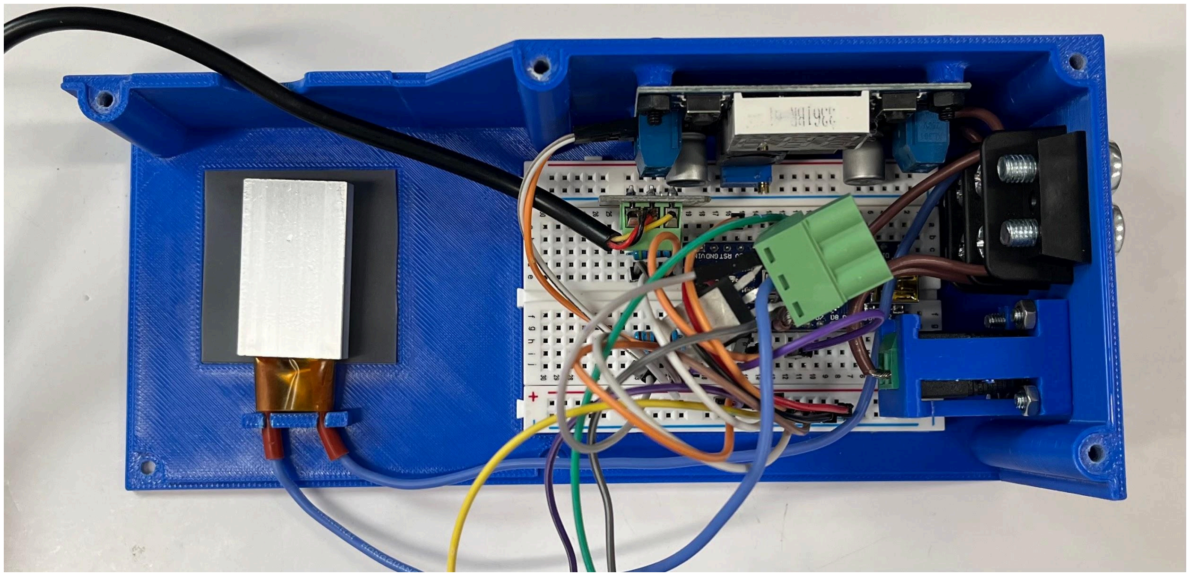
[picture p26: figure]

9. Get four 65mm M3 screws, two 45mm M3 screws, and six M3 hex nuts. Screw in both halves of the enclosure together. Make sure to avoid pinching any wires between the two parts of the enclosure.
10. With the temperature sensor passing through the rectangular hole of the enclosure, sit the cable in the circular indent so that the heating block can slide in.
11. Place the sensor inside one of the smaller holes in the heating block to maximize surface area contact and get more accurate measurements.

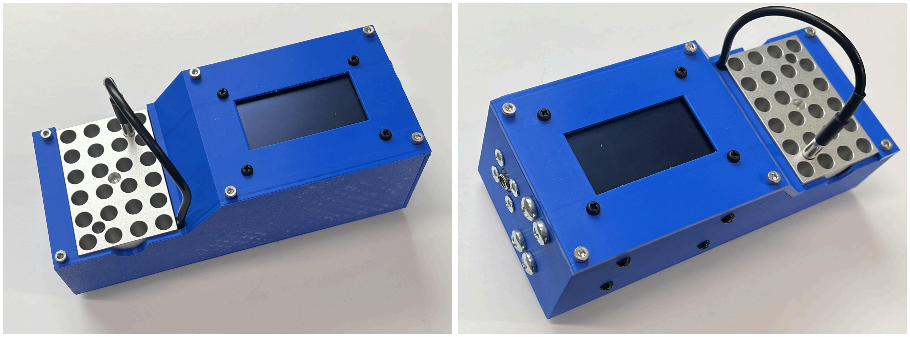
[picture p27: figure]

Updated on 09/18/2026

Congratulations on assembling your sherBLOCK! The sherBLOCK is now fully assembled and ready to use.

Whenever you desire, you may remove the arduino board from the breadboard to upload new code. We designed the sherBLOCK to minimize the number of parts that need to be removed during this process, so you only need to remove the heating block and open the enclosure once again (being careful with the wires connected to the OLED on the lid). You can then fit a small screwdriver into the breadboard center divider and gently pry the arduino board up. Just make sure to double check the positioning of the arduino once you are placing it back on the breadboard (useful tips are to take pictures of the circuit before you make any changes and to use a pen to mark where the arduino sits on the breadboard).

Please keep in mind that the sherBLOCK heater can get much hotter than the heating block, so avoid leaving it on when the heating block is not in place. Since the heater is regulated by the temperature measurements taken by the sensor, removing the sensor from the heating block will lead to unregulated heating output. Still, there are safety measures in the code to prevent overheating in case the sensor is not coupled to the heating block.

We hope you enjoy your sherBLOCK experience! Feel free to reach out to us on GitHub if you have any questions, suggestions, or concerns.

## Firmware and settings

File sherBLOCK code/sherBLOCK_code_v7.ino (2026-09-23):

#include <Wire.h>
#include <Adafruit_GFX.h>
#include <Adafruit_SSD1306.h>
#include <OneWire.h>
#include <DallasTemperature.h>
//#include <Fonts/FreeSans9pt7b.h>

// 'BootFrame1', 128x64px
const unsigned char BootFramesBootFrame1 [] PROGMEM = {
	0x00, 0x00, 0x00, 0x00, 0x00, 0x00, 0x00, 0x00, 0x00, 0x00, 0x00, 0x00, 0x00, 0x00, 0x00, 0x00, 
	0x00, 0x00, 0x00, 0x00, 0x00, 0x00, 0x00, 0x00, 0x00, 0x00, 0x00, 0x00, 0x00, 0x00, 0x00, 0x00, 
	0x00, 0x00, 0x00, 0x00, 0x00, 0x00, 0x00, 0x00, 0x00, 0x00, 0x00, 0x00, 0x00, 0x00, 0x00, 0x00, 
	0x00, 0x00, 0x00, 0x00, 0x00, 0x00, 0x00, 0x00, 0x00, 0x00, 0x00, 0x00, 0x00, 0x00, 0x00, 0x00, 
	0x00, 0x00, 0x00, 0x00, 0x00, 0x00, 0x00, 0x00, 0x00, 0x00, 0x00, 0x00, 0x00, 0x00, 0x00, 0x00, 
	0x00, 0x00, 0x00, 0x00, 0x00, 0x00, 0x00, 0x00, 0x00, 0x00, 0x00, 0x00, 0x00, 0x00, 0x00, 0x00, 
	0x00, 0x00, 0x00, 0x00, 0x00, 0x00, 0x00, 0x00, 0x00, 0x00, 0x00, 0x00, 0x00, 0x00, 0x00, 0x00, 
	0x00, 0x00, 0x00, 0x00, 0x00, 0x00, 0x00, 0x00, 0x00, 0x00, 0x00, 0x00, 0x00, 0x00, 0x00, 0x00, 
	0x00, 0x00, 0x00, 0x00, 0x00, 0x00, 0x00, 0x00, 0x00, 0x00, 0x00, 0x00, 0x00, 0x00, 0x00, 0x00, 
	0x00, 0x00, 0x00, 0x00, 0x00, 0x00, 0x00, 0x00, 0x00, 0x00, 0x00, 0x00, 0x00, 0x00, 0x00, 0x00, 
	0x00, 0x00, 0x00, 0x00, 0x00, 0x00, 0x00, 0x00, 0x00, 0x00, 0x00, 0x00, 0x00, 0x00, 0x00, 0x00, 
	0x00, 0x00, 0x00, 0x00, 0x04, 0x00, 0x00, 0x00, 0x00, 0x00, 0x00, 0x00, 0x00, 0x00, 0x00, 0x00, 
	0x00, 0x00, 0x00, 0x00, 0x04, 0x00, 0x00, 0x00, 0x00, 0x00, 0x00, 0x00, 0x00, 0x00, 0x00, 0x00, 
	0x00, 0x00, 0x00, 0x00, 0x06, 0x00, 0x00, 0x00, 0x00, 0x00, 0x00, 0x00, 0x00, 0x00, 0x00, 0x00, 
	0x00, 0x00, 0x00, 0x00, 0x83, 0x10, 0x00, 0x00, 0x00, 0x00, 0x00, 0x00, 0x00, 0x00, 0x00, 0x00, 
	0x00, 0x00, 0x00, 0x00, 0xc3, 0x98, 0x00, 0x00, 0x00, 0x00, 0x00, 0x00, 0x00, 0x00, 0x00, 0x00, 
	0x00, 0x00, 0x00, 0x00, 0x61, 0x8c, 0x00, 0x00, 0x00, 0x00, 0x00, 0x00, 0x00, 0x00, 0x00, 0x00, 
	0x00, 0x00, 0x00, 0x00, 0x61, 0x8c, 0x00, 0x00, 0x00, 0x00, 0x00, 0x00, 0x00, 0x00, 0x00, 0x00, 
	0x00, 0x00, 0x00, 0x00, 0x61, 0x8c, 0x00, 0x00, 0x00, 0x00, 0x00, 0x00, 0x00, 0x00, 0x00, 0x00, 
	0x00, 0x00, 0x00, 0x00, 0x63, 0x8c, 0x00, 0x00, 0x00, 0x00, 0x00, 0x00, 0x00, 0x00, 0x00, 0x00, 
	0x00, 0x00, 0x00, 0x00, 0xc7, 0x18, 0x00, 0x00, 0x00, 0x00, 0x00, 0x00, 0x00, 0x00, 0x00, 0x00, 
	0x00, 0x00, 0x00, 0x00, 0xc6, 0x18, 0x00, 0x00, 0x00, 0x00, 0x00, 0x00, 0x00, 0x00, 0x00, 0x00, 
	0x00, 0x00, 0x00, 0x01, 0x86, 0x30, 0x00, 0x00, 0x00, 0x00, 0x00, 0x00, 0x00, 0x00, 0x00, 0x00, 
	0x00, 0x00, 0x00, 0x01, 0x86, 0x30, 0x00, 0x00, 0x00, 0x00, 0x00, 0x00, 0x00, 0x00, 0x00, 0x00, 
	0x00, 0x00, 0x00, 0x01, 0x86, 0x30, 0x00, 0x00, 0x00, 0x00, 0x00, 0x00, 0x00, 0x00, 0x00, 0x00, 
	0x00, 0x00, 0x00, 0x00, 0xc7, 0x18, 0x00, 0x00, 0x00, 0x00, 0x00, 0x00, 0x00, 0x00, 0x00, 0x00, 
	0x00, 0x00, 0x00, 0x00, 0xc3, 0x18, 0x1f, 0xff, 0xff, 0xff, 0xff, 0xff, 0xff, 0xfc, 0x00, 0x00, 
	0x00, 0x00, 0x00, 0x78, 0x41, 0x08, 0x1f, 0xff, 0xff, 0xff, 0xff, 0xff, 0xff, 0xfc, 0x00, 0x00, 
	0x00, 0x00, 0x00, 0x38, 0x41, 0x08, 0x18, 0x03, 0x83, 0xf8, 0x3f, 0x05, 0x06, 0x0c, 0x00, 0x00, 
	0x00, 0x00, 0x00, 0x38, 0x00, 0x00, 0x1c, 0x71, 0xc7, 0xf3, 0xce, 0x79, 0x8f, 0x3c, 0x00, 0x00, 
	0x00, 0x00, 0x00, 0x38, 0x00, 0x00, 0x1c, 0x71, 0xc7, 0xe3, 0xcc, 0x7d, 0x8e, 0xfc, 0x00, 0x00, 
	0x00, 0x00, 0x0f, 0x3b, 0x87, 0x9e, 0xdc, 0x73, 0xc7, 0xe3, 0xc4, 0x7d, 0x89, 0xfc, 0x00, 0x00, 
	0x00, 0x00, 0x1d, 0x3d, 0xce, 0xcf, 0xdc, 0x03, 0xc7, 0xe3, 0xc4, 0x7f, 0x80, 0xfc, 0x00, 0x00, 
	0x00, 0x00, 0x1e, 0x39, 0xcf, 0xce, 0x1c, 0x71, 0xc7, 0xe3, 0xc4, 0x7f, 0x88, 0x7c, 0x00, 0x00, 
	0x00, 0x00, 0x0f, 0x39, 0xce, 0x0e, 0x1c, 0x71, 0xc7, 0xa3, 0xcc, 0x7d, 0x8c, 0x3c, 0x00, 0x00, 
	0x00, 0x00, 0x13, 0x39, 0xce, 0x4e, 0x1c, 0x71, 0xc7, 0x33, 0xce, 0x7b, 0x8e, 0x1c, 0x00, 0x00, 
	0x00, 0x00, 0x1f, 0x7d, 0xe7, 0x9f, 0x18, 0x03, 0x80, 0x38, 0x3f, 0x07, 0x04, 0x0c, 0x00, 0x00, 
	0x00, 0x00, 0x00, 0x00, 0x00, 0x00, 0x1f, 0xff, 0xff, 0xff, 0xff, 0xff, 0xff, 0xfc, 0x00, 0x00, 
	0x00, 0x00, 0x00, 0x00, 0x00, 0x00, 0x1f, 0xff, 0xff, 0xff, 0xff, 0xff, 0xff, 0xfc, 0x00, 0x00, 
	0x00, 0x00, 0x00, 0x00, 0x00, 0x00, 0x00, 0x00, 0x00, 0x00, 0x00, 0x00, 0x00, 0x00, 0x00, 0x00, 
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
};
// 'BootFrame2', 128x64px
const unsigned char BootFramesBootFrame2 [] PROGMEM = {
	0x00, 0x00, 0x00, 0x00, 0x00, 0x00, 0x00, 0x00, 0x00, 0x00, 0x00, 0x00, 0x00, 0x00, 0x00, 0x00, 
	0x00, 0x00, 0x00, 0x00, 0x00, 0x00, 0x00, 0x00, 0x00, 0x00, 0x00, 0x00, 0x00, 0x00, 0x00, 0x00, 
	0x00, 0x00, 0x00, 0x00, 0x00, 0x00, 0x00, 0x00, 0x00, 0x00, 0x00, 0x00, 0x00, 0x00, 0x00, 0x00, 
	0x00, 0x00, 0x00, 0x00, 0x00, 0x00, 0x00, 0x00, 0x00, 0x00, 0x00, 0x00, 0x00, 0x00, 0x00, 0x00, 
	0x00, 0x00, 0x00, 0x00, 0x00, 0x00, 0x00, 0x00, 0x00, 0x00, 0x00, 0x00, 0x00, 0x00, 0x00, 0x00, 
	0x00, 0x00, 0x00, 0x00, 0x00, 0x00, 0x00, 0x00, 0x00, 0x00, 0x00, 0x00, 0x00, 0x00, 0x00, 0x00, 
	0x00, 0x00, 0x00, 0x00, 0x00, 0x00, 0x00, 0x00, 0x00, 0x00, 0x00, 0x00, 0x00, 0x00, 0x00, 0x00, 
	0x00, 0x00, 0x00, 0x00, 0x00, 0x00, 0x00, 0x00, 0x00, 0x00, 0x00, 0x00, 0x00, 0x00, 0x00, 0x00, 
	0x00, 0x00, 0x00, 0x00, 0x04, 0x00, 0x00, 0x00, 0x00, 0x00, 0x00, 0x00, 0x00, 0x00, 0x00, 0x00, 
	0x00, 0x00, 0x00, 0x00, 0x04, 0x00, 0x00, 0x00, 0x00, 0x00, 0x00, 0x00, 0x00, 0x00, 0x00, 0x00, 
	0x00, 0x00, 0x00, 0x00, 0x0c, 0x00, 0x00, 0x00, 0x00, 0x00, 0x00, 0x00, 0x00, 0x00, 0x00, 0x00, 
	0x00, 0x00, 0x00, 0x00, 0x0c, 0x20, 0x00, 0x00, 0x00, 0x00, 0x00, 0x00, 0x00, 0x00, 0x00, 0x00, 
	0x00, 0x00, 0x00, 0x01, 0x0e, 0x30, 0x00, 0x00, 0x00, 0x00, 0x00, 0x00, 0x00, 0x00, 0x00, 0x00, 
	0x00, 0x00, 0x00, 0x01, 0x87, 0x18, 0x00, 0x00, 0x00, 0x00, 0x00, 0x00, 0x00, 0x00, 0x00, 0x00, 
	0x00, 0x00, 0x00, 0x00, 0xc3, 0x08, 0x00, 0x00, 0x00, 0x00, 0x00, 0x00, 0x00, 0x00, 0x00, 0x00, 
	0x00, 0x00, 0x00, 0x00, 0xc3, 0x8c, 0x00, 0x00, 0x00, 0x00, 0x00, 0x00, 0x00, 0x00, 0x00, 0x00, 
	0x00, 0x00, 0x00, 0x00, 0x61, 0x8c, 0x00, 0x00, 0x00, 0x00, 0x00, 0x00, 0x00, 0x00, 0x00, 0x00, 
	0x00, 0x00, 0x00, 0x00, 0x61, 0x86, 0x00, 0x00, 0x00, 0x00, 0x00, 0x00, 0x00, 0x00, 0x00, 0x00, 
	0x00, 0x00, 0x00, 0x00, 0x61, 0x86, 0x00, 0x00, 0x00, 0x00, 0x00, 0x00, 0x00, 0x00, 0x00, 0x00, 
	0x00, 0x00, 0x00, 0x00, 0x63, 0x0e, 0x00, 0x00, 0x00, 0x00, 0x00, 0x00, 0x00, 0x00, 0x00, 0x00, 
	0x00, 0x00, 0x00, 0x00, 0x67, 0x0c, 0x00, 0x00, 0x00, 0x00, 0x00, 0x00, 0x00, 0x00, 0x00, 0x00, 
	0x00, 0x00, 0x00, 0x00, 0xc6, 0x18, 0x00, 0x00, 0x00, 0x00, 0x00, 0x00, 0x00, 0x00, 0x00, 0x00, 
	0x00, 0x00, 0x00, 0x01, 0x86, 0x38, 0x00, 0x00, 0x00, 0x00, 0x00, 0x00, 0x00, 0x00, 0x00, 0x00, 
	0x00, 0x00, 0x00, 0x01, 0x87, 0x30, 0x00, 0x00, 0x00, 0x00, 0x00, 0x00, 0x00, 0x00, 0x00, 0x00, 
	0x00, 0x00, 0x00, 0x01, 0xc3, 0x30, 0x00, 0x00, 0x00, 0x00, 0x00, 0x00, 0x00, 0x00, 0x00, 0x00, 
	0x00, 0x00, 0x00, 0x00, 0xc3, 0x10, 0x00, 0x00, 0x00, 0x00, 0x00, 0x00, 0x00, 0x00, 0x00, 0x00, 
	0x00, 0x00, 0x00, 0x00, 0x41, 0x08, 0x1f, 0xff, 0xff, 0xff, 0xff, 0xff, 0xff, 0xfc, 0x00, 0x00, 
	0x00, 0x00, 0x00, 0x78, 0x01, 0x00, 0x1f, 0xff, 0xff, 0xff, 0xff, 0xff, 0xff, 0xfc, 0x00, 0x00, 
	0x00, 0x00, 0x00, 0x38, 0x10, 0x10, 0x18, 0x03, 0x83, 0xf8, 0x3f, 0x05, 0x06, 0x0c, 0x00, 0x00, 
	0x00, 0x00, 0x00, 0x38, 0x00, 0x00, 0x1c, 0x71, 0xc7, 0xf3, 0xce, 0x79, 0x8f, 0x3c, 0x00, 0x00, 
	0x00, 0x00, 0x00, 0x38, 0x00, 0x00, 0x1c, 0x71, 0xc7, 0xe3, 0xcc, 0x7d, 0x8e, 0xfc, 0x00, 0x00, 
	0x00, 0x00, 0x0f, 0x3b, 0x87, 0x9e, 0xdc, 0x73, 0xc7, 0xe3, 0xc4, 0x7d, 0x89, 0xfc, 0x00, 0x00, 
	0x00, 0x00, 0x1d, 0x3d, 0xce, 0xcf, 0xdc, 0x03, 0xc7, 0xe3, 0xc4, 0x7f, 0x80, 0xfc, 0x00, 0x00, 
	0x00, 0x00, 0x1e, 0x39, 0xcf, 0xce, 0x1c, 0x71, 0xc7, 0xe3, 0xc4, 0x7f, 0x88, 0x7c, 0x00, 0x00, 
	0x00, 0x00, 0x0f, 0x39, 0xce, 0x0e, 0x1c, 0x71, 0xc7, 0xa3, 0xcc, 0x7d, 0x8c, 0x3c, 0x00, 0x00, 
	0x00, 0x00, 0x13, 0x39, 0xce, 0x4e, 0x1c, 0x71, 0xc7, 0x33, 0xce, 0x7b, 0x8e, 0x1c, 0x00, 0x00, 
	0x00, 0x00, 0x1f, 0x7d, 0xe7, 0x9f, 0x18, 0x03, 0x80, 0x38, 0x3f, 0x07, 0x04, 0x0c, 0x00, 0x00, 
	0x00, 0x00, 0x00, 0x00, 0x00, 0x00, 0x1f, 0xff, 0xff, 0xff, 0xff, 0xff, 0xff, 0xfc, 0x00, 0x00, 
	0x00, 0x00, 0x00, 0x00, 0x00, 0x00, 0x1f, 0xff, 0xff, 0xff, 0xff, 0xff, 0xff, 0xfc, 0x00, 0x00, 
	0x00, 0x00, 0x00, 0x00, 0x00, 0x00, 0x00, 0x00, 0x00, 0x00, 0x00, 0x00, 0x00, 0x00, 0x00, 0x00, 
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
};
// 'BootFrame3', 128x64px
const unsigned char BootFramesBootFrame3 [] PROGMEM = {
	0x00, 0x00, 0x00, 0x00, 0x00, 0x00, 0x00, 0x00, 0x00, 0x00, 0x00, 0x00, 0x00, 0x00, 0x00, 0x00, 
	0x00, 0x00, 0x00, 0x00, 0x00, 0x00, 0x00, 0x00, 0x00, 0x00, 0x00, 0x00, 0x00, 0x00, 0x00, 0x00, 
	0x00, 0x00, 0x00, 0x00, 0x00, 0x00, 0x00, 0x00, 0x00, 0x00, 0x00, 0x00, 0x00, 0x00, 0x00, 0x00, 
	0x00, 0x00, 0x00, 0x00, 0x00, 0x00, 0x00, 0x00, 0x00, 0x00, 0x00, 0x00, 0x00, 0x00, 0x00, 0x00, 
	0x00, 0x00, 0x00, 0x00, 0x00, 0x00, 0x00, 0x00, 0x00, 0x00, 0x00, 0x00, 0x00, 0x00, 0x00, 0x00, 
	0x00, 0x00, 0x00, 0x00, 0x00, 0x00, 0x00, 0x00, 0x00, 0x00, 0x00, 0x00, 0x00, 0x00, 0x00, 0x00, 
	0x00, 0x00, 0x00, 0x00, 0x00, 0x00, 0x00, 0x00, 0x00, 0x00, 0x00, 0x00, 0x00, 0x00, 0x00, 0x00, 
	0x00, 0x00, 0x00, 0x00, 0x04, 0x00, 0x00, 0x00, 0x00, 0x00, 0x00, 0x00, 0x00, 0x00, 0x00, 0x00, 
	0x00, 0x00, 0x00, 0x00, 0x04, 0x00, 0x00, 0x00, 0x00, 0x00, 0x00, 0x00, 0x00, 0x00, 0x00, 0x00, 
	0x00, 0x00, 0x00, 0x00, 0x0c, 0x08, 0x00, 0x00, 0x00, 0x00, 0x00, 0x00, 0x00, 0x00, 0x00, 0x00, 
	0x00, 0x00, 0x00, 0x00, 0x8c, 0x10, 0x00, 0x00, 0x00, 0x00, 0x00, 0x00, 0x00, 0x00, 0x00, 0x00, 
	0x00, 0x00, 0x00, 0x00, 0x8e, 0x30, 0x00, 0x00, 0x00, 0x00, 0x00, 0x00, 0x00, 0x00, 0x00, 0x00, 
	0x00, 0x00, 0x00, 0x01, 0x8e, 0x30, 0x00, 0x00, 0x00, 0x00, 0x00, 0x00, 0x00, 0x00, 0x00, 0x00, 
	0x00, 0x00, 0x00, 0x01, 0x87, 0x38, 0x00, 0x00, 0x00, 0x00, 0x00, 0x00, 0x00, 0x00, 0x00, 0x00, 
	0x00, 0x00, 0x00, 0x01, 0xc7, 0x18, 0x00, 0x00, 0x00, 0x00, 0x00, 0x00, 0x00, 0x00, 0x00, 0x00, 
	0x00, 0x00, 0x00, 0x00, 0xe3, 0x1c, 0x00, 0x00, 0x00, 0x00, 0x00, 0x00, 0x00, 0x00, 0x00, 0x00, 
	0x00, 0x00, 0x00, 0x00, 0x61, 0x9c, 0x00, 0x00, 0x00, 0x00, 0x00, 0x00, 0x00, 0x00, 0x00, 0x00, 
	0x00, 0x00, 0x00, 0x00, 0x61, 0x8c, 0x00, 0x00, 0x00, 0x00, 0x00, 0x00, 0x00, 0x00, 0x00, 0x00, 
	0x00, 0x00, 0x00, 0x00, 0x63, 0x8c, 0x00, 0x00, 0x00, 0x00, 0x00, 0x00, 0x00, 0x00, 0x00, 0x00, 
	0x00, 0x00, 0x00, 0x00, 0x67, 0x0c, 0x00, 0x00, 0x00, 0x00, 0x00, 0x00, 0x00, 0x00, 0x00, 0x00, 
	0x00, 0x00, 0x00, 0x00, 0xe6, 0x1c, 0x00, 0x00, 0x00, 0x00, 0x00, 0x00, 0x00, 0x00, 0x00, 0x00, 
	0x00, 0x00, 0x00, 0x01, 0xc6, 0x18, 0x00, 0x00, 0x00, 0x00, 0x00, 0x00, 0x00, 0x00, 0x00, 0x00, 
	0x00, 0x00, 0x00, 0x01, 0xc7, 0x30, 0x00, 0x00, 0x00, 0x00, 0x00, 0x00, 0x00, 0x00, 0x00, 0x00, 
	0x00, 0x00, 0x00, 0x01, 0x87, 0x30, 0x00, 0x00, 0x00, 0x00, 0x00, 0x00, 0x00, 0x00, 0x00, 0x00, 
	0x00, 0x00, 0x00, 0x01, 0x83, 0x30, 0x00, 0x00, 0x00, 0x00, 0x00, 0x00, 0x00, 0x00, 0x00, 0x00, 
	0x00, 0x00, 0x00, 0x00, 0x81, 0x10, 0x00, 0x00, 0x00, 0x00, 0x00, 0x00, 0x00, 0x00, 0x00, 0x00, 
	0x00, 0x00, 0x00, 0x00, 0x81, 0x10, 0x1f, 0xff, 0xff, 0xff, 0xff, 0xff, 0xff, 0xfc, 0x00, 0x00, 
	0x00, 0x00, 0x00, 0x78, 0x22, 0x00, 0x1f, 0xff, 0xff, 0xff, 0xff, 0xff, 0xff, 0xfc, 0x00, 0x00, 
	0x00, 0x00, 0x00, 0x38, 0x00, 0x20, 0x18, 0x03, 0x83, 0xf8, 0x3f, 0x05, 0x06, 0x0c, 0x00, 0x00, 
	0x00, 0x00, 0x00, 0x38, 0x00, 0x00, 0x1c, 0x71, 0xc7, 0xf3, 0xce, 0x79, 0x8f, 0x3c, 0x00, 0x00, 
	0x00, 0x00, 0x00, 0x38, 0x00, 0x00, 0x1c, 0x71, 0xc7, 0xe3, 0xcc, 0x7d, 0x8e, 0xfc, 0x00, 0x00, 
	0x00, 0x00, 0x0f, 0x3b, 0x87, 0x9e, 0xdc, 0x73, 0xc7, 0xe3, 0xc4, 0x7d, 0x89, 0xfc, 0x00, 0x00, 
	0x00, 0x00, 0x1d, 0x3d, 0xce, 0xcf, 0xdc, 0x03, 0xc7, 0xe3, 0xc4, 0x7f, 0x80, 0xfc, 0x00, 0x00, 
	0x00, 0x00, 0x1e, 0x39, 0xcf, 0xce, 0x1c, 0x71, 0xc7, 0xe3, 0xc4, 0x7f, 0x88, 0x7c, 0x00, 0x00, 
	0x00, 0x00, 0x0f, 0x39, 0xce, 0x0e, 0x1c, 0x71, 0xc7, 0xa3, 0xcc, 0x7d, 0x8c, 0x3c, 0x00, 0x00, 
	0x00, 0x00, 0x13, 0x39, 0xce, 0x4e, 0x1c, 0x71, 0xc7, 0x33, 0xce, 0x7b, 0x8e, 0x1c, 0x00, 0x00, 
	0x00, 0x00, 0x1f, 0x7d, 0xe7, 0x9f, 0x18, 0x03, 0x80, 0x38, 0x3f, 0x07, 0x04, 0x0c, 0x00, 0x00, 
	0x00, 0x00, 0x00, 0x00, 0x00, 0x00, 0x1f, 0xff, 0xff, 0xff, 0xff, 0xff, 0xff, 0xfc, 0x00, 0x00, 
	0x00, 0x00, 0x00, 0x00, 0x00, 0x00, 0x1f, 0xff, 0xff, 0xff, 0xff, 0xff, 0xff, 0xfc, 0x00, 0x00, 
	0x00, 0x00, 0x00, 0x00, 0x00, 0x00, 0x00, 0x00, 0x00, 0x00, 0x00, 0x00, 0x00, 0x00, 0x00, 0x00, 
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
};
// 'BootFrame4', 128x64px
const unsigned char BootFramesBootFrame4 [] PROGMEM = {
	0x00, 0x00, 0x00, 0x00, 0x00, 0x00, 0x00, 0x00, 0x00, 0x00, 0x00, 0x00, 0x00, 0x00, 0x00, 0x00, 
	0x00, 0x00, 0x00, 0x00, 0x00, 0x00, 0x00, 0x00, 0x00, 0x00, 0x00, 0x00, 0x00, 0x00, 0x00, 0x00, 
	0x00, 0x00, 0x00, 0x00, 0x00, 0x00, 0x00, 0x00, 0x00, 0x00, 0x00, 0x00, 0x00, 0x00, 0x00, 0x00, 
	0x00, 0x00, 0x00, 0x00, 0x00, 0x00, 0x00, 0x00, 0x00, 0x00, 0x00, 0x00, 0x00, 0x00, 0x00, 0x00, 
	0x00, 0x00, 0x00, 0x00, 0x00, 0x00, 0x00, 0x00, 0x00, 0x00, 0x00, 0x00, 0x00, 0x00, 0x00, 0x00, 
	0x00, 0x00, 0x00, 0x00, 0x01, 0x00, 0x00, 0x00, 0x00, 0x00, 0x00, 0x00, 0x00, 0x00, 0x00, 0x00, 
	0x00, 0x00, 0x00, 0x00, 0x01, 0x00, 0x00, 0x00, 0x00, 0x00, 0x00, 0x00, 0x00, 0x00, 0x00, 0x00, 
	0x00, 0x00, 0x00, 0x00, 0x03, 0x00, 0x00, 0x00, 0x00, 0x00, 0x00, 0x00, 0x00, 0x00, 0x00, 0x00, 
	0x00, 0x00, 0x00, 0x00, 0x03, 0x04, 0x00, 0x00, 0x00, 0x00, 0x00, 0x00, 0x00, 0x00, 0x00, 0x00, 
	0x00, 0x00, 0x00, 0x00, 0x87, 0x0c, 0x00, 0x00, 0x00, 0x00, 0x00, 0x00, 0x00, 0x00, 0x00, 0x00, 
	0x00, 0x00, 0x00, 0x00, 0x86, 0x08, 0x00, 0x00, 0x00, 0x00, 0x00, 0x00, 0x00, 0x00, 0x00, 0x00, 
	0x00, 0x00, 0x00, 0x01, 0x86, 0x08, 0x00, 0x00, 0x00, 0x00, 0x00, 0x00, 0x00, 0x00, 0x00, 0x00, 
	0x00, 0x00, 0x00, 0x01, 0x86, 0x18, 0x00, 0x00, 0x00, 0x00, 0x00, 0x00, 0x00, 0x00, 0x00, 0x00, 
	0x00, 0x00, 0x00, 0x00, 0x86, 0x18, 0x00, 0x00, 0x00, 0x00, 0x00, 0x00, 0x00, 0x00, 0x00, 0x00, 
	0x00, 0x00, 0x00, 0x00, 0xc7, 0x18, 0x00, 0x00, 0x00, 0x00, 0x00, 0x00, 0x00, 0x00, 0x00, 0x00, 
	0x00, 0x00, 0x00, 0x00, 0x47, 0x0c, 0x00, 0x00, 0x00, 0x00, 0x00, 0x00, 0x00, 0x00, 0x00, 0x00, 
	0x00, 0x00, 0x00, 0x00, 0x67, 0x8c, 0x00, 0x00, 0x00, 0x00, 0x00, 0x00, 0x00, 0x00, 0x00, 0x00, 
	0x00, 0x00, 0x00, 0x00, 0x63, 0x8c, 0x00, 0x00, 0x00, 0x00, 0x00, 0x00, 0x00, 0x00, 0x00, 0x00, 
	0x00, 0x00, 0x00, 0x00, 0xe1, 0x8e, 0x00, 0x00, 0x00, 0x00, 0x00, 0x00, 0x00, 0x00, 0x00, 0x00, 
	0x00, 0x00, 0x00, 0x00, 0xe1, 0x8e, 0x00, 0x00, 0x00, 0x00, 0x00, 0x00, 0x00, 0x00, 0x00, 0x00, 
	0x00, 0x00, 0x00, 0x01, 0xe3, 0x8c, 0x00, 0x00, 0x00, 0x00, 0x00, 0x00, 0x00, 0x00, 0x00, 0x00, 
	0x00, 0x00, 0x00, 0x01, 0xc3, 0x0c, 0x00, 0x00, 0x00, 0x00, 0x00, 0x00, 0x00, 0x00, 0x00, 0x00, 
	0x00, 0x00, 0x00, 0x00, 0xc3, 0x18, 0x00, 0x00, 0x00, 0x00, 0x00, 0x00, 0x00, 0x00, 0x00, 0x00, 
	0x00, 0x00, 0x00, 0x00, 0xe3, 0x10, 0x00, 0x00, 0x00, 0x00, 0x00, 0x00, 0x00, 0x00, 0x00, 0x00, 
	0x00, 0x00, 0x00, 0x00, 0x21, 0x00, 0x00, 0x00, 0x00, 0x00, 0x00, 0x00, 0x00, 0x00, 0x00, 0x00, 
	0x00, 0x00, 0x00, 0x00, 0x00, 0x00, 0x00, 0x00, 0x00, 0x00, 0x00, 0x00, 0x00, 0x00, 0x00, 0x00, 
	0x00, 0x00, 0x00, 0x00, 0x00, 0x00, 0x1f, 0xff, 0xff, 0xff, 0xff, 0xff, 0xff, 0xfc, 0x00, 0x00, 
	0x00, 0x00, 0x00, 0x78, 0x00, 0x00, 0x1f, 0xff, 0xff, 0xff, 0xff, 0xff, 0xff, 0xfc, 0x00, 0x00, 
	0x00, 0x00, 0x00, 0x38, 0x00, 0x00, 0x18, 0x03, 0x83, 0xf8, 0x3f, 0x05, 0x06, 0x0c, 0x00, 0x00, 
	0x00, 0x00, 0x00, 0x38, 0x00, 0x00, 0x1c, 0x71, 0xc7, 0xf3, 0xce, 0x79, 0x8f, 0x3c, 0x00, 0x00, 
	0x00, 0x00, 0x00, 0x38, 0x00, 0x00, 0x1c, 0x71, 0xc7, 0xe3, 0xcc, 0x7d, 0x8e, 0xfc, 0x00, 0x00, 
	0x00, 0x00, 0x0f, 0x3b, 0x87, 0x9e, 0xdc, 0x73, 0xc7, 0xe3, 0xc4, 0x7d, 0x89, 0xfc, 0x00, 0x00, 
	0x00, 0x00, 0x1d, 0x3d, 0xce, 0xcf, 0xdc, 0x03, 0xc7, 0xe3, 0xc4, 0x7f, 0x80, 0xfc, 0x00, 0x00, 
	0x00, 0x00, 0x1e, 0x39, 0xcf, 0xce, 0x1c, 0x71, 0xc7, 0xe3, 0xc4, 0x7f, 0x88, 0x7c, 0x00, 0x00, 
	0x00, 0x00, 0x0f, 0x39, 0xce, 0x0e, 0x1c, 0x71, 0xc7, 0xa3, 0xcc, 0x7d, 0x8c, 0x3c, 0x00, 0x00, 
	0x00, 0x00, 0x13, 0x39, 0xce, 0x4e, 0x1c, 0x71, 0xc7, 0x33, 0xce, 0x7b, 0x8e, 0x1c, 0x00, 0x00, 
	0x00, 0x00, 0x1f, 0x7d, 0xe7, 0x9f, 0x18, 0x03, 0x80, 0x38, 0x3f, 0x07, 0x04, 0x0c, 0x00, 0x00, 
	0x00, 0x00, 0x00, 0x00, 0x00, 0x00, 0x1f, 0xff, 0xff, 0xff, 0xff, 0xff, 0xff, 0xfc, 0x00, 0x00, 
	0x00, 0x00, 0x00, 0x00, 0x00, 0x00, 0x1f, 0xff, 0xff, 0xff, 0xff, 0xff, 0xff, 0xfc, 0x00, 0x00, 
	0x00, 0x00, 0x00, 0x00, 0x00, 0x00, 0x00, 0x00, 0x00, 0x00, 0x00, 0x00, 0x00, 0x00, 0x00, 0x00, 
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
};

// Array of all bitmaps for convenience. (Total bytes used to store images in PROGMEM = 4160)
const int BootFramesallArray_LEN = 4;
const unsigned char* BootFramesallArray[4] = {
	BootFramesBootFrame1,
	BootFramesBootFrame2,
	BootFramesBootFrame3,
	BootFramesBootFrame4
};

// OLED setup
#define SCREEN_WIDTH 128
#define SCREEN_HEIGHT 64
Adafruit_SSD1306 display(SCREEN_WIDTH, SCREEN_HEIGHT, &Wire, -1);

// Sensor (DS18B20) pin
#define ONE_WIRE_BUS 2
OneWire oneWire(ONE_WIRE_BUS);
DallasTemperature sensors(&oneWire);

// Heater setup
const int HEAT_GATE = 5; // MOSFET PWM-capable Heat Gate pin

// Heater control parameters
bool safetyShutdown = false;
const float TEMP_SETPOINT = 37.0;
const float TEMP_50_START = 34;
const float TEMP_20_START = 35;
const float TEMP_OFF_AT   = 37.0;

// Temperature regulation variables
float previousTemp = NAN;
unsigned long lastStoreTime = 0;
const unsigned long storeInterval = 30000;   // 30 seconds

// PWM values
const int PWM_OFF  = 0;
const int PWM_20   = 51;    // about 20% of 255, so around 20% heater power
const int PWM_50   = 128;   // about 50% heater power
const int PWM_100  = 255;   // 100% heater power

int heaterPWM = 0;

//const int VENT_GATE = 4; not currently using a vent

//bool ventOn = false;

void showBootAnimation() {
  for (int cycle = 0; cycle < 3; cycle++) {
    display.clearDisplay();
    display.drawBitmap(0, 0, BootFramesBootFrame1, 128, 64, SSD1306_WHITE);
    display.display();
    delay(250);

    display.clearDisplay();
    display.drawBitmap(0, 0, BootFramesBootFrame2, 128, 64, SSD1306_WHITE);
    display.display();
    delay(250);

    display.clearDisplay();
    display.drawBitmap(0, 0, BootFramesBootFrame3, 128, 64, SSD1306_WHITE);
    display.display();
    delay(250);

    display.clearDisplay();
    display.drawBitmap(0, 0, BootFramesBootFrame4, 128, 64, SSD1306_WHITE);
    display.display();
    delay(250);
  }
}
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
void loop() {
	
	unsigned long now = millis();

// Read temperature
  sensors.requestTemperatures();
  float currentTemp = sensors.getTempCByIndex(0);

// Storing past temperatures
	//Serial.print("now: "); Serial.print(now);
	//Serial.print(" lastStoreTime: "); Serial.print(lastStoreTime);
	//Serial.print(" elapsed: "); Serial.println(now - lastStoreTime);
	if (!safetyShutdown && now - lastStoreTime >= storeInterval) {
			Serial.println("=== Protection check running ===");
			//Serial.print(" cond1: "); Serial.print(currentTemp < previousTemp + 1);
			//Serial.print(" cond2: "); Serial.println(currentTemp <= TEMP_50_START);
			if (!safetyShutdown && currentTemp < previousTemp + 0.2 && currentTemp <= TEMP_OFF_AT - 1) {  // Overheating safety feature
				setHeaterPWM(PWM_OFF);
				safetyShutdown = true;
				Serial.print("Overheating protection activated");
			 } 				
			lastStoreTime = now;
			previousTemp = currentTemp; // Store the latest measured value
	}

// Heater control with stepped PWM
	if (safetyShutdown) {
			setHeaterPWM(PWM_OFF); // Heater off if overheating protection was activated
	} else {
			if (currentTemp == DEVICE_DISCONNECTED_C) {
			setHeaterPWM(PWM_OFF);
		} else {
			if (currentTemp < TEMP_50_START) {
				setHeaterPWM(PWM_100);
			} else if (currentTemp < TEMP_20_START) {
				setHeaterPWM(PWM_50);
			} else if (currentTemp < TEMP_OFF_AT) {
				setHeaterPWM(PWM_20);
			} else {
				setHeaterPWM(PWM_OFF);
			}
		}
	}
  
// Vent gate control
  //if (!ventOn && currentTemp >= OFF_ABOVE + 0.5) {
  //  setVent(true);
  //} else if (ventOn && currentTemp <= ON_BELOW + 0.5) {
  //  setVent(false);
  //}

// Serial output on terminal
  //Serial.print(F("Temperature: "));
  //if (currentTemp == DEVICE_DISCONNECTED_C) {
    //Serial.println(F("ERR"));
  //} else {
    //Serial.print(currentTemp, 1);
    //Serial.write((uint8_t)248); // degree symbol for many Windows terminals
    //Serial.println(F("C"));
  //}

  //Serial.print(F(" | Heater PWM: "));
  //Serial.print(heaterPWM);

  Serial.print(F(" | Power: "));
  if (heaterPWM == PWM_OFF) {
    Serial.println(F("OFF"));
  } else if (heaterPWM == PWM_20) {
    Serial.println(F("20%"));
  } else if (heaterPWM == PWM_50) {
    Serial.println(F("50%"));
  } else {
    Serial.println(F("100%"));
  }

  display.clearDisplay();

  char tempLine[24];
  char tempStr[10];
	char overrideLine[30];
  char heaterLine[20];
  char setTempStr[10];
  char setTempLine[25];

if (safetyShutdown) {
			snprintf(setTempLine, sizeof(setTempLine), "OVERRIDE ON");
			drawCentreString(setTempLine, 10);
			snprintf(tempLine, sizeof(tempLine), "check sensor");
			drawCentreString(tempLine, 30);
			snprintf(heaterLine, sizeof(heaterLine), "restart device");
			drawCentreString(heaterLine, 50);
	} else if (currentTemp == DEVICE_DISCONNECTED_C || currentTemp == -127) {
			strcpy(tempLine, "Temperature: ERROR");
	}	else {
			dtostrf(TEMP_SETPOINT, 0, 1, setTempStr);
			snprintf(setTempLine, sizeof(setTempLine), "Set to: %s%cC", setTempStr, 248);   //OLED target temp set
			dtostrf(currentTemp, 0, 1, tempStr);                                            //OLED current temp status
			snprintf(tempLine, sizeof(tempLine), "Temperature: %s%cC", tempStr, 248); 
			snprintf(heaterLine, sizeof(heaterLine), "Heater: %s",                          //OLED Heater Power status 
				(heaterPWM == PWM_OFF) ? "OFF" :
				(heaterPWM == PWM_20)  ? "20%" :
				(heaterPWM == PWM_50)  ? "50%" : "100%");
	}
	drawCentreString(setTempLine, 10);
	drawCentreString(tempLine, 30);
	drawCentreString(heaterLine, 50);
	display.display();
	delay(1000);
}

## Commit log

2026-09-10 Create sherBLOCK assembly guide
2026-09-10 Update sherBLOCK assembly guide
2026-09-23 Rename sherBLOCK v5.FCStd to Print files/sherBLOCK v5
2026-09-23 Rename sherBLOCK BOM - Sheet1.csv to sherBLOCK BOM.csv
    [sherBLOCK BOM.csv]
2026-10-02 Create Printing specifications
2026-11-03 Update Printing specifications
2026-11-05 Update and rename Printing specifications to Printing specifications.md
2026-11-05 Rename Print files/sherBLOCK_10A_v1.5-Base Base body.stl to Print files/sherBLOCK+/sherBLOCK+_v1.5-Base Base body.stl
2026-11-05 Rename sherBLOCK+_v1.5-Base Base body.stl to sherBLOCK+_v1.5-base.stl
2026-11-05 Rename Print files/sherBLOCK_10A_v1.5-10A adapter enclosureadapter enclosure body.stl to Print files/sherBLOCK+/sherBLOCK+_v1.5-adapter.stl
2026-11-05 Rename Print files/sherBLOCK_10A_v1.5-Fused lidFused lid body.stl to Print files/sherBLOCK+/sherBLOCK+_v1.5-lid.stl
2026-11-05 Rename Print files/sherBLOCK_2A_v1.0.FCStd to Print files/sherBLOCK/sherBLOCK_2A_v1.0.FCStd
2026-11-05 Rename sherBLOCK+ Bill of Materials (BOM) - 10A model______eadsheet.xlsx to sherBLOCK BOMs/sherBLOCK+_BOM-10A model.xlsx
2026-11-05 Rename sherBLOCK BOM (1).xlsx to sherBLOCK BOMs/sherBLOCK_BOM-2Amodel.xlsx
2026-11-05 Rename sherBLOCK assembly guide to sherBLOCK assembly guide.md
2026-11-12 Update Printing specifications.md
